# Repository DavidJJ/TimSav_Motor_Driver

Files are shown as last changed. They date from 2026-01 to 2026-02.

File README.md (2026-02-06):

# TimSav Motor Driver 

The EdwardERC TimSav is a CNC cutter for foamboard that uses a needle connected to a motor to cut the board.
It uses a servo to raise and lower the needle (Z-axis). This is accomplished by repurposing the spindle speed 
as a PWM output for the servo.  Unfortunately, GRBL only supports one PWM output, so this means the motor has 
to be turned on by hand using a servo tester. 

This project allows the motor to be controlled with GRBL by repurposing the coolant function to act as a toggle.
It uses a second Arduino to listen for the mode input to turn the motor on or off. 

This project does not allow the CNC Shield to control the speed of the motor. That is set by the user using the 
potentiometer. 

## How to use
- To turn the motor on, Add an `M8` command to the start of the G-code.
- To turn the motor off, Add an `M9` command to the end of the G-code.
- I have modified the Timsav-Inskcape plugin to add the `M8` and `M9` commands to the G-code.
 - [Modified TimSav Inkscape Plugin](https://github.com/DavidJJ/inkscape-timsav/tree/FEATURE/Cooling-as-motor-controller) 

## Built For
- Board: Arduino Nano (ATmega328P)
- Framework: Arduino
- PlatformIO environment: `env:nanoatmega328`

## Behavior
- PWM output: pin 9 via Servo library (~50 Hz refresh)
- Mode input: digital pin 2
  - HIGH: Turn the motor on according to the speed set by the potentiometer.
  - LOW: Turn the motor off.

## Pulse Width Range
- Potentiometer maps to 1000us - 2000us
- Limits can be adjusted in `src/main.cpp`

## Wiring
- Potentiometer
  - wiper to A0, 
  - one end to +5V 
  - one end to GND
- Mode input to D2 
  - 10k ohm pull-down resistor from D2 to GND.
  - Coolant Pin on the CNC shield `CoolEn A3` connects to D2 on Arduino `J1 Pin 2`  
  - Ground pin on the CNC Shiled `GND` connects to GND on Arduino `J1 Pin 1`
- ESC output
  - D9 to ESC signal output `J2 Pin 3`
  - +5V to middle pin of `J2 Pin 2`
  - GND to outside pin of `J2 Pin 1`
- Test Button (Optional)
  - +5V to pin 1 of the test button
  - D2 to pin 2 of the test button

## Diagram
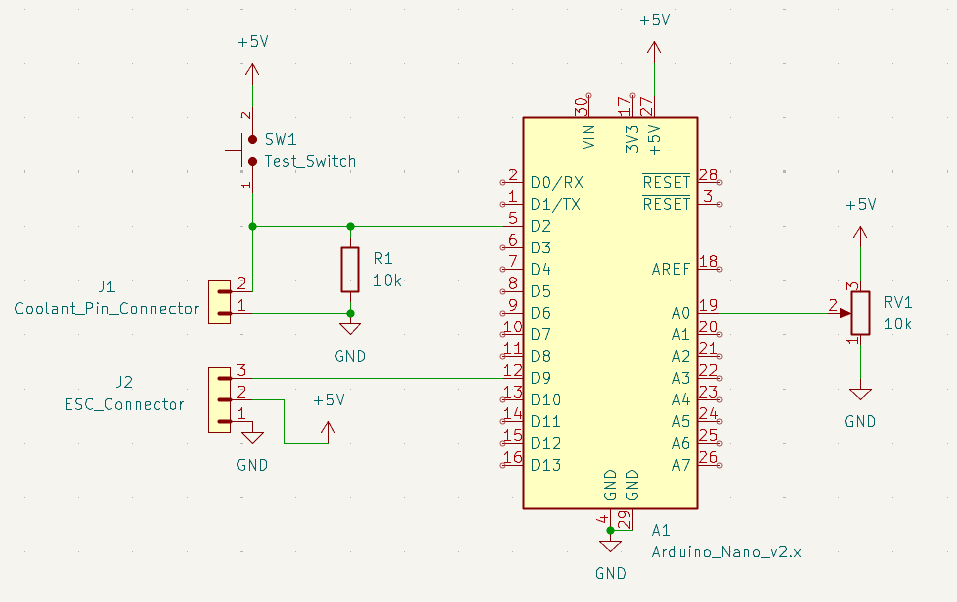
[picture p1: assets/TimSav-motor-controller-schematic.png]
Wire-Diagram

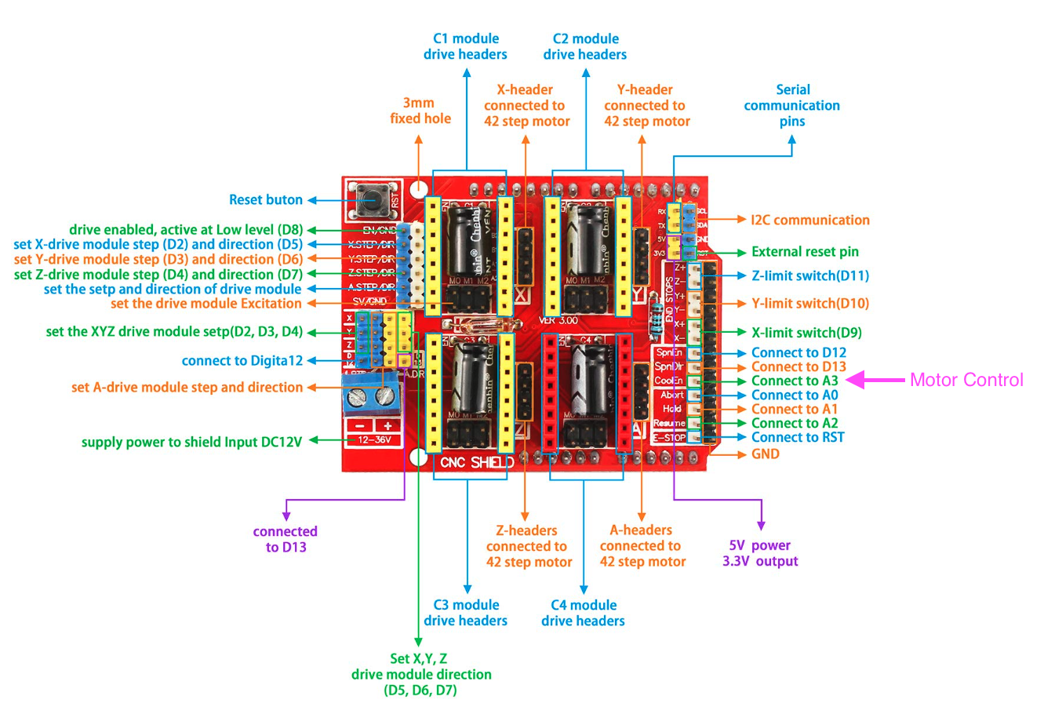
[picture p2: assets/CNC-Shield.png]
CNC-Shield


## Build/Upload
```sh
pio run # build project
pio run -t upload # upload to board
```

## Monitor serial connection
```sh
pio device monitor
```

## Links
 - [TimSav](https://www.etsy.com/listing/1374647661/erc-timsav-cheap-diy-cnc-foamboard)
 - [Modified design](https://www.thingiverse.com/thing:5442906)
 - [Inkscape Plugin](https://github.com/DavidJJ/inkscape-timsav/tree/FEATURE/Cooling-as-motor-controller)

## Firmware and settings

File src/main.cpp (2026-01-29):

#include <Arduino.h>
#include <Servo.h>

#define DEBUG 0

namespace {
    constexpr uint8_t kPwmPin = 9;
    constexpr uint8_t kPotPin = A0;
    constexpr uint8_t kModePin = 2;
    constexpr int kMotorOffPulseUs = 1000;
    constexpr int kMinCommandPulseUs = 1000;
    constexpr int kMaxCommandPulseUs = 2000;
} // namespace

Servo pwmServo;

void setup() {
#if DEBUG
    Serial.begin(9600);
#endif
    // Set mode pin to INPUT.
    // The motor/potentiometer mode will be active when the pin is LOW.
    pinMode(kModePin, INPUT);
    pinMode(LED_BUILTIN, OUTPUT);
    pwmServo.attach(kPwmPin, kMinCommandPulseUs, kMaxCommandPulseUs);

    pwmServo.writeMicroseconds(kMotorOffPulseUs);
#if DEBUG
    Serial.println("Motor Driver Initialized");
#endif
}

void loop() {
    const bool use_pot = digitalRead(kModePin) == HIGH;
    digitalWrite(LED_BUILTIN, use_pot ? HIGH : LOW);
    if (use_pot) {
        const int pot_value = analogRead(kPotPin);
        const int pulse_us = map(pot_value, 0, 1023, kMinCommandPulseUs, kMaxCommandPulseUs);
        pwmServo.writeMicroseconds(pulse_us);
#if DEBUG
        Serial.print("Mode: Potentiometer, Pulse: ");
        Serial.print(pulse_us);
        Serial.println(" us");
#endif
    } else {
        pwmServo.writeMicroseconds(kMotorOffPulseUs);
#if DEBUG
        Serial.println("Mode: Fixed (Off)");
#endif
    }

    delay(15);
}

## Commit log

2026-01-27 Initial commit
    This is a little Arduino project that allows you to control a servo / ESC using a potentiometer and an on-off pin.
    It's meant to use with the Tim-Sav project so that you can wire the on-off pin to the "cooling" pin of a GRBL based CNC board and use that to turn the motor on and off without needing to output PWM o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
2026-01-29 use the servo library. put debug behind a flag.
2026-02-01 Add license, clarify that mode input goes to coolant pin on the CNC shield.
2026-02-03 Update the documentation to be more clear. Add in the schematic files.
    [timsav-motor-controller.kicad_pcb, timsav-motor-controller.kicad_sch]
